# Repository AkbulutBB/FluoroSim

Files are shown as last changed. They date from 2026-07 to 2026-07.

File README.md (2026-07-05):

# FluoroSim 2.0 — gVXR Synthetic Fluoroscopy Navigation

Radiation-free pedicle screw placement training. Synthetic AP + lateral X-ray
images are generated directly from CAD/STL using **gVXR**, with a two-cube
ArUco probe tracked by two webcams and overlaid in real time.

No real fluoroscopy. No DLT calibration. No image-intensifier distortion. The
entire coordinate chain is defined in CAD, so every projection is exact.

---

## Why this architecture

The previous DLT-from-real-fluoroscopy approach was floored at 11–15 px
reprojection error by image-intensifier distortion (pincushion + S-distortion)
that cannot be estimated from 8 sparse fiducials. gVXR sidesteps this entirely:
the X-ray is **generated** from the STL with exact pinhole geometry, so the
3D→2D projection is analytically known and invertible. The steel bearings now
appear in the synthetic image at their exact CAD positions as a built-in
visual sanity check.

---

## Coordinate chain (zero physical calibration)

```
Camera  ──[ChArUco detect]──►  Board frame
Board   ──[BOARD_TO_WORLD]──►  gVXR world = CAD platform origin
World   ──[hard-stop slide]──► Spine STL origin
```

Every transform is exact by design. The only value you measure is
`BOARD_TO_WORLD` — and that comes from Fusion, not from a calibration session.

---

## Install

```bash
pip install opencv-contrib-python==4.9.0.80 numpy Pillow gvxr
```

`opencv-contrib-python` is pinned to 4.9.0.80 for numpy<2 compatibility in
the Anaconda base environment. gVXR provides `gvxrPython3`.

---

## First-run setup

### 1. Export STLs from Fusion 360
File → 3D Print → STL, units = **millimetres**:
- `models/spine.stl`
- `models/platform.stl` (optional)

### 2. Fill in CAD values in `config.py`
Four things, all read from your Fusion assembly:

| Value | What it is |
|---|---|
| `BEARING_POSITIONS` | (X,Y,Z) of each steel bearing centre in platform space |
| `SPINE_ORIGIN_IN_WORLD` | spine origin at its seated hard-stop position |
| `BOARD_TO_WORLD` | 4×4 rigid transform: ChArUco board origin → platform space |
| `SPINE_STL_PATH` / `PLATFORM_STL_PATH` | STL file locations |

### 3. Verify gVXR
```bash
python tools/test_gvxr.py
```
Should print `ALL TESTS PASSED` and produce `test_ap.png`, `test_lat.png`.

### 4. Calibrate both cameras (checkerboard intrinsics)
```bash
python tools/calibrate_intrinsics.py --device 0 --out data/intrinsics/cam0.npz
python tools/calibrate_intrinsics.py --device 1 --out data/intrinsics/cam1.npz
```

### 5. Print the probe markers
```bash
python tools/make_probe_sheet.py --out probe_sheet.pdf --dpi 300
```
Print at **100% scale** (no fit-to-page). Verify with the 50 mm scale bar.

---

## Run

```bash
python main.py
```

1. **Render X-ray Background** — generates AP + LAT from the STL (once, ~1–3 s)
2. **Start** — begins dual-camera tracking
3. Move the probe; its trajectory overlays live on both views (~5 Hz, 3 ms overlay)
4. **Photorealistic Snapshot** — re-renders with the K-wire as an actual
   tungsten/steel cylinder casting a true X-ray shadow (~2–10 s)

---

## Probe design (two stacked cubes)

- Two **40 mm cubes**, 5 mm spacer, 45 mm centre-to-centre pitch
- **32 mm** ArUco markers (DICT_4X4_50), one per side face, 4 faces per cube
- Bottom cube: IDs 0–3. Top cube: IDs 4–7.
- **100 mm K-wire** collinear with the probe axis, exiting the bottom cube's
  −Z face, tip 120 mm below the bottom-cube centre.

**Gluing rule:** Hold the probe handle-up / tip-down. The bottom edge of every
marker faces the K-wire tip. Both cubes oriented identically. Print cubes in
white PETG so the cube face itself serves as the ArUco quiet zone.

Fusing all visible faces from both cubes in a single solvePnP (plus VVS
refinement) gives far stronger angular constraints than any single face. Two
cameras at ~45° oblique (corner-on, each seeing two adjacent faces per cube)
constrain the pose best.

---

## Module map

```
config.py                 All geometry, camera, gVXR, and CAD parameters
main.py                   Entry point

core/
  camera.py               Threaded webcam capture + intrinsic I/O
  markers.py              BoardTracker + ProbeTracker (ChArUco + two-cube)
  navigation.py           Dual-camera pose fusion → world-space tip/base
  xray_sim.py             gVXR wrapper: render + analytic overlay + snapshot

ui/
  app.py                  Tkinter app: previews + AP/LAT panels + live overlay

tools/
  test_gvxr.py            gVXR install + render verification
  calibrate_intrinsics.py Checkerboard intrinsic calibration
  make_probe_sheet.py     A4 marker sheet with round-trip self-check

models/                   spine.stl, platform.stl  (your CAD exports)
data/
  intrinsics/             cam0.npz, cam1.npz  (saved calibration)
```

---

## gVXR 2.1 initialisation order (important)

gVXR is strict about call order — deviating produces silently all-zero images
with no error. The required sequence (handled inside `xray_sim.py`):

1. `createNewContext`
2. Create meshes / assign materials / position them
3. `setSourcePosition` → `usePointSource`
4. `resetBeamSpectrum` → `addEnergyBinToSpectrumPerPixelAtSDD`
   (`setMonoChromatic` and `addEnergyBinToSpectrum` are deprecated)
5. `setDetectorPosition` → `setDetectorUpVector`
6. `setDetectorNumberOfPixels` → `setDetectorPixelSize`
7. `addPolygonMeshAsOuterSurface` (register meshes — **after** steps 3–6)
8. `computeXRayImage`

To switch views, redo 3–6 and recompute; registered meshes persist.

On Windows/Anaconda set `GVXR_CONTEXT = "OPENGL"`; on a headless Linux box use
`"EGL"`.

---

## Error budget

| Source | Contribution |
|---|---|
| Spine hard-stop play | ≤ 1 mm (consistent, could be zeroed in CAD) |
| Probe reprojection (two-cube, dual-cam) | target < 15 px → ~ sub-mm tip |
| CAD-defined transforms | exact |
| **Total target** | **< 5 mm, < 5°** |

---

*Reference for marker-based AR neuronavigation methods: Yavas et al.,
Neurosurg Focus 2021.*

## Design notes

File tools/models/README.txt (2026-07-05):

Place your CAD exports here:
  spine.stl      (required — export from Fusion 360 in mm)
  platform.stl   (optional)

If spine.stl is missing, the simulator falls back to a cuboid placeholder
so you can test the pipeline before exporting.

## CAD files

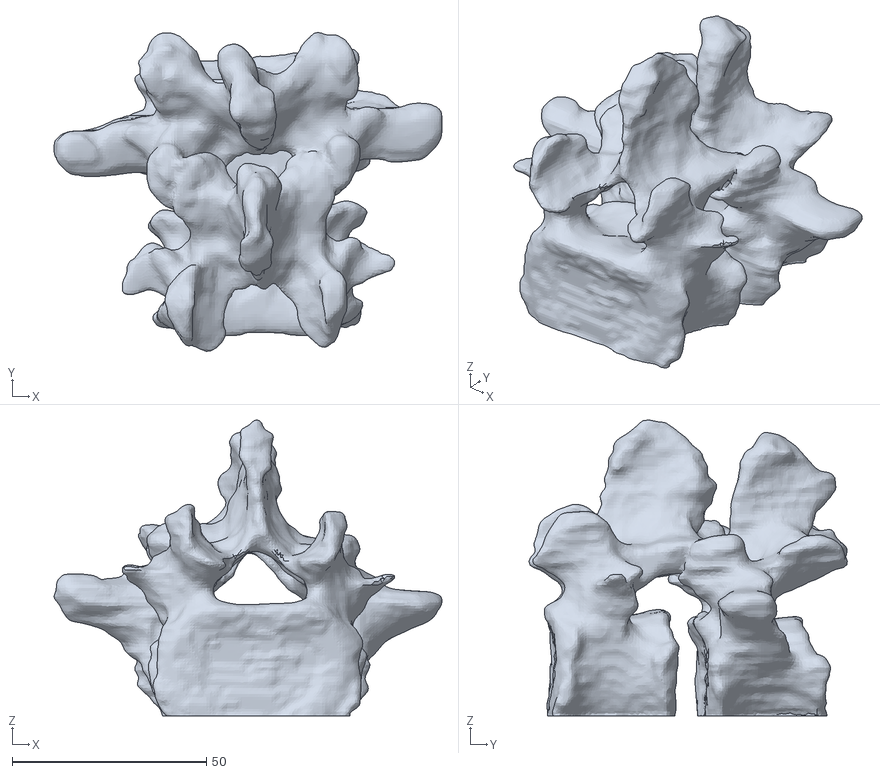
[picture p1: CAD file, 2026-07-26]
outputs/render_cache/spine_clipped.stl
99.8 x 82.0 x 76.1

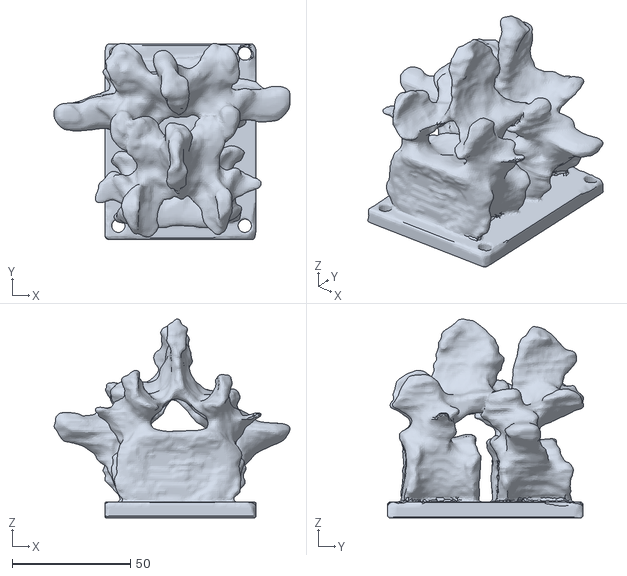
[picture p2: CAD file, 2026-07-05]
tools/models/spine.stl
99.8 x 83.0 x 84.1

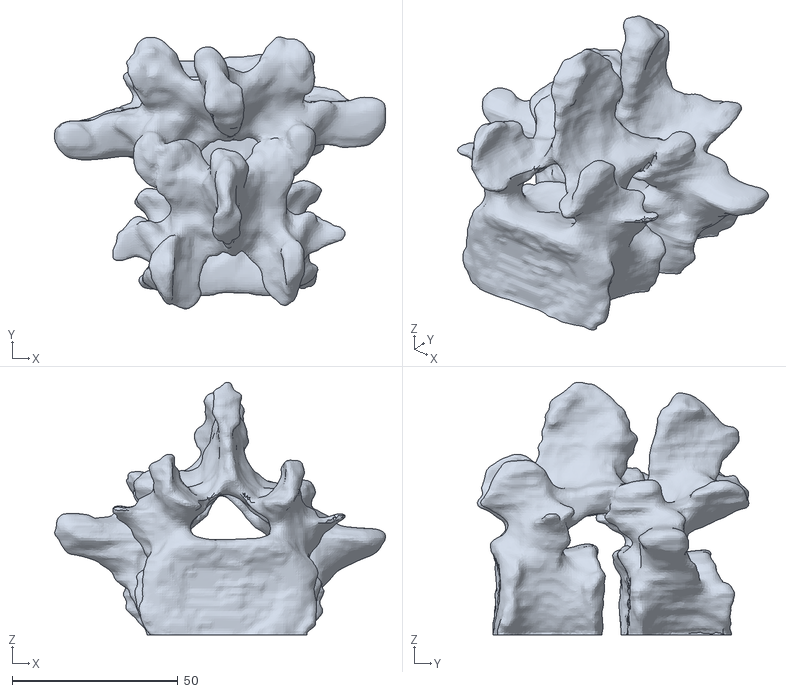
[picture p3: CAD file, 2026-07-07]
tools/outputs/stl_preview/spine_shell.stl
99.8 x 82.0 x 76.1

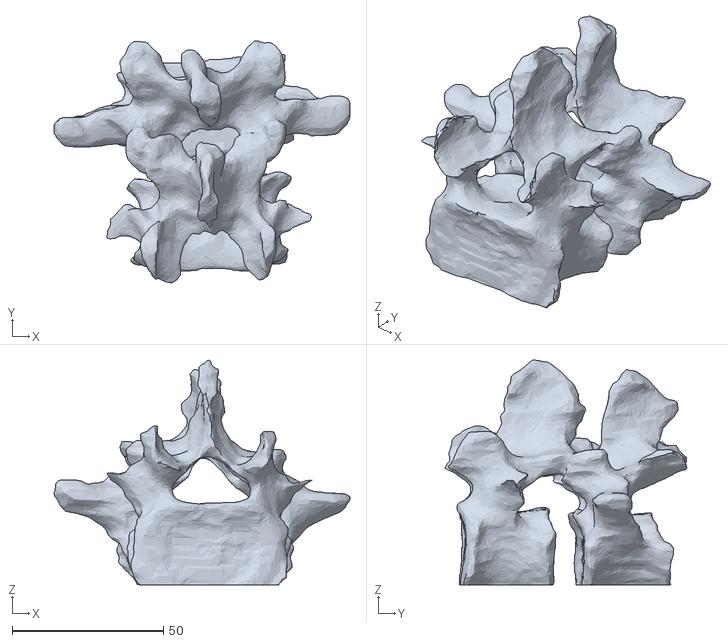
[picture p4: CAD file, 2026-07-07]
tools/outputs/stl_preview/spine_core.stl
97.9 x 80.1 x 74.3

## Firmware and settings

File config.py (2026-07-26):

"""
config.py — FluoroSim complete configuration.

All physical measurements in millimetres.

SETUP CHECKLIST
===============
Before first run, fill in the sections marked  ← FROM CAD  by reading the
values from your Fusion 360 assembly.  Everything else works as-is.

1. Export STLs from Fusion (File → 3D Print → STL, units = mm):
       models/spine.stl
       models/platform.stl   (optional)

2. Fill in BEARING_POSITIONS from Fusion assembly coordinates.
3. Fill in SPINE_TO_WORLD (spine local->platform rigid transform, rotation
   included -- do NOT assume translation-only; see derivation notes below).
4. Fill in BOARD_TO_WORLD (ChArUco board origin + orientation in platform frame).
5. Run tools/test_gvxr.py — confirm "ALL TESTS PASSED".
6. Run main.py.
"""

import cv2
import numpy as np

# ─────────────────────────────────────────────────────────────────────────────
# ArUco / ChArUco dictionaries
# ─────────────────────────────────────────────────────────────────────────────

ARUCO_PROBE_DICT_ID   = cv2.aruco.DICT_4X4_50
ARUCO_PROBE_DICT      = cv2.aruco.getPredefinedDictionary(ARUCO_PROBE_DICT_ID)

CHARUCO_BOARD_DICT_ID = cv2.aruco.DICT_5X5_50
CHARUCO_BOARD_DICT    = cv2.aruco.getPredefinedDictionary(CHARUCO_BOARD_DICT_ID)

# ─────────────────────────────────────────────────────────────────────────────
# ChArUco platform board
# ─────────────────────────────────────────────────────────────────────────────

CHARUCO_COLS        = 7      # number of squares horizontally
CHARUCO_ROWS        = 4      # number of squares vertically
CHARUCO_SQUARE_MM   = 18.0   # physical square side length (mm)
CHARUCO_MARKER_MM   = 13.5   # printed ArUco marker size inside each square
                              # (= 0.75 × square; adjust to match your print)

# ─────────────────────────────────────────────────────────────────────────────
# Two-cube probe geometry
# ─────────────────────────────────────────────────────────────────────────────
#
# Probe body frame:
#   Origin = bottom cube centre (the cube adjacent to the K-wire)
#   +Z axis = pointing toward the top/handle cube
#   K-wire exits from the −Z face of the bottom cube, 100 mm long
#   Top cube centre is at +45 mm along Z (40 mm cubes, 5 mm spacer)
#
#   Marker IDs:
#     Bottom cube: four side faces, IDs 0–3  (+X, −X, +Y, −Y)
#     Top    cube: four side faces, IDs 4–7  (+X, −X, +Y, −Y)
#

CUBE_SIDE_MM   = 40.0    # cube side length (mm)
MARKER_SIZE_MM = 32.0    # marker printed size per face (mm)
CUBE_GAP_MM    = 45.0    # bottom→top cube centre distance (40 mm + 5 mm spacer)
ROD_LENGTH_MM  = 100.0   # K-wire length from bottom cube face to tip

_h = MARKER_SIZE_MM / 2.0   # half marker side = 16 mm
_s = CUBE_SIDE_MM   / 2.0   # half cube side   = 20 mm
_g = CUBE_GAP_MM             # 45 mm

# ── Per-cube yaw about the probe long axis (+Z) ──────────────────────────────
# One cube is physically mounted rotated 45 deg relative to the other, so that
# any camera sees TWO faces per cube (corner-on) instead of one face-on. This
# gives more independent angular constraints in the joint PnP solve.
#
# Only the RELATIVE yaw between the two cubes affects accuracy. A global yaw of
# the whole probe is harmless here because the K-wire is coaxial with +Z
# (ROD_TIP_IN_PROBE lies on the Z axis), so rotating the entire probe about Z
# changes neither the tip position nor the trajectory direction.
#
# SIGN IS NOT YET FIELD-VERIFIED. +45 and -45 differ by 90 deg, which is a
# relabeling of which marker ID sits on which face — so a wrong sign is a real
# error in the model of the cubes' RELATIVE orientation, and it will corrupt any
# solve that uses markers from both cubes at once. It is easy to detect and fix:
# see "Verifying the yaw sign" below.
PROBE_CUBE_BOTTOM_YAW_DEG = 45.0   # cube with the K-wire — mounted corner-on
PROBE_CUBE_TOP_YAW_DEG    = 0.0    # handle-side cube — faces axis-aligned

# Verifying the yaw sign
# ----------------------
# Watch the probe reprojection RMS reported by the tracker while holding the
# probe so BOTH cubes are visible to one camera:
#   * low, stable RMS (a few px)      -> relative yaw is modeled correctly
#   * large RMS, or RMS that is fine  -> relative yaw is off by 90 deg;
#     on single-cube views but jumps     flip the sign below to -45.0
#     when the second cube appears
# Single-cube RMS looks fine under either sign, so judge it only on frames
# where both cubes are detected.
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

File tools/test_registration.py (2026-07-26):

"""
tools/test_registration.py — Registration sanity check, no hardware required.

Unlike stl_xray_preview.py (which deliberately ignores BOARD_TO_WORLD and
SPINE_TO_WORLD to test the spine STL/material in isolation), this script
renders the REAL config.py exactly as main.py's live app would — spine
mesh placed via SPINE_TO_WORLD, bearings placed via BEARING_POSITIONS, both
in the same gVXR world frame — but with zero camera, board, or probe
involved. It answers one question: "given today's config.py values, does
the spine + bearing geometry actually look/measure like a coherent scene?"

Run this AFTER tools/test_gvxr.py (confirms gVXR itself works) and BEFORE
main.py (which additionally needs cameras, an intrinsic calibration, and
the physical rig).

Checks performed
-----------------
1. Renders AP + lateral backgrounds (spine + 8 bearings) via the real
   XRaySimulator(config) — the exact same call ui/app.py makes.
2. Numerically projects every BEARING_POSITIONS entry through both views'
   pinhole geometry and reports whether each lands inside the detector
   frame. A bearing projecting off-frame usually means GVXR_ISOCENTER is
   far from where the bearings/spine actually are, not a rendering bug.
3. Reports the spine mesh's world-space bounding box (via trimesh, if
   installed) so you can eyeball whether it's anywhere near the bearings
   and isocentre, before even opening the PNGs.

Usage
-----
    python tools/test_registration.py

Output
------
    outputs/registration_test/ap_background.png
    outputs/registration_test/lat_background.png

What to look for in the PNGs
-----------------------------
- Bearings should appear as small bright dots roughly along the spine's
  periphery (not floating in empty background space, not buried deep
  inside/outside the visible anatomy).
- AP and LAT should look like two different projections of the SAME
  object, not two unrelated renders.
- If the spine is offset far to one side or mostly/entirely off-frame,
  SPINE_TO_WORLD is very likely still wrong (check rotation sign/axis
  first — that's the part solved from the fewest points).
"""

from __future__ import annotations

import sys
from pathlib import Path

import cv2
import numpy as np

sys.path.insert(0, str(Path(__file__).resolve().parents[1]))

import config as cfg  # noqa: E402
from core.xray_sim import XRaySimulator, GVXR_AVAILABLE  # noqa: E402

# Bearings live on the platform, not the spine, and are off by default for
# trainee-facing renders -- but they are the whole point of this test, so
# force them on for this run only.
cfg.RENDER_BEARINGS = True

try:
    import trimesh
    TRIMESH_AVAILABLE = True
except ImportError:
    trimesh = None  # type: ignore
    TRIMESH_AVAILABLE = False

OUTDIR = Path("outputs/registration_test")

# BGR (OpenCV order)
GREEN = (0, 255, 0)


def annotate_bearings(gray: np.ndarray, carm, bearings, world_to_spine) -> np.ndarray:
    """
    Draw a labelled green ring at each bearing's ANALYTICALLY projected pixel
    position on a colour copy of the grayscale render.

    gVXR output is an X-ray attenuation map — single-channel by physics — so a
    bearing cannot be "coloured" inside the render itself. Instead we project
    each bearing's known CAD position through the same pinhole geometry the
    renderer used (VirtualCArm.project_point) and mark it.

    This doubles as an independent cross-check: the ring is computed from the
    transform chain + projection maths, while the white dot underneath it comes
    from gVXR's ray-casting through the actual sphere mesh. If ring and dot
    coincide, both paths agree. If they are offset, one of them is wrong — and
    the pixel gap is a direct readout of the registration error.
    """
    rgb = cv2.cvtColor(gray, cv2.COLOR_GRAY2BGR)
    n_drawn = 0
    for b in bearings:
        pos_world = np.append(np.asarray(b["position_mm"], dtype=np.float64), 1.0)
        pos_render = (np.asarray(world_to_spine, dtype=np.float64) @ pos_world)[:3]
        px = carm.project_point(pos_render)
        if px is None:
            continue
        col, row = px
        # Ring, not filled disc — so the rendered bearing stays visible inside.
        cv2.circle(rgb, (col, row), 10, GREEN, 1, cv2.LINE_AA)
        cv2.putText(rgb, str(b["label"]), (col + 14, row + 4),
                    cv2.FONT_HERSHEY_SIMPLEX, 0.4, GREEN, 1, cv2.LINE_AA)
        n_drawn += 1
    cv2.putText(rgb, f"{n_drawn} bearing(s) in frame", (8, 20),
                cv2.FONT_HERSHEY_SIMPLEX, 0.45, GREEN, 1, cv2.LINE_AA)
    return rgb


def main() -> int:
    if not GVXR_AVAILABLE:
        print("gvxrPython3 is not importable in this environment. "
              "Run tools/test_gvxr.py first.", file=sys.stderr)
        return 1

    print("=" * 60)
    print("FluoroSim — Registration Sanity Check (no hardware)")
    print("=" * 60)

    spine_path = Path(cfg.SPINE_STL_PATH)
    print(f"Spine STL     : {spine_path}  "
          f"({'found' if spine_path.exists() else 'MISSING -> cuboid placeholder will be used'})")
    print(f"BOARD_TO_WORLD:\n{np.round(np.asarray(cfg.BOARD_TO_WORLD), 3)}")
    print(f"SPINE_TO_WORLD:\n{np.round(np.asarray(cfg.SPINE_TO_WORLD), 3)}")
    print(f"BOARD_TO_SPINE (derived, render frame):\n"
          f"{np.round(np.asarray(cfg.BOARD_TO_SPINE), 3)}")
    print(f"Isocentre     : {cfg.GVXR_ISOCENTER if cfg.GVXR_ISOCENTER is not None else 'AUTO (clipped spine bbox centre)'}")
    print(f"Baseplate clip: {cfg.SPINE_CLIP_MM} mm along local {cfg.SPINE_CLIP_AXIS}")
    print(f"Bearings      : {len(cfg.BEARING_POSITIONS)} configured")

    if TRIMESH_AVAILABLE and spine_path.exists():
        try:
            m = trimesh.load_mesh(str(spine_path), force="mesh")
            print(f"Spine bbox (spine-local = RENDER frame, unclipped): "
                  f"min={m.bounds[0].round(1)}  max={m.bounds[1].round(1)}")
        except Exception as exc:
            print(f"  (bbox check skipped: {exc})")

    # Where does the ChArUco board origin land in the render frame? This is the
    # single number that ties the tracker to the anatomy -- if it is nowhere
    # near the spine bbox above, the probe will render in the wrong place.
    board_origin_render = (np.asarray(cfg.BOARD_TO_SPINE)
                           @ np.array([0.0, 0.0, 0.0, 1.0]))[:3]
    print(f"ChArUco origin in render frame: {board_origin_render.round(2)}")

    OUTDIR.mkdir(parents=True, exist_ok=True)

    sim = XRaySimulator(cfg)
    print("\nInitialising gVXR context + scene ... ", end="", flush=True)
    if not sim.initialise():
        print("FAILED — see log above.", file=sys.stderr)
        return 1
    print("OK")

    print("Rendering AP + lateral (spine + bearings) ... ", end="", flush=True)
    ap_img, lat_img = sim.render_background()
    if ap_img is None or lat_img is None:
        print("FAILED — render_background() returned None.", file=sys.stderr)
        sim.shutdown()
        return 1
    print("OK")

    ap_path = OUTDIR / "ap_background.png"
    lat_path = OUTDIR / "lat_background.png"
    cv2.imwrite(str(ap_path), ap_img)
    cv2.imwrite(str(lat_path), lat_img)

    # Annotated copies: green labelled rings at the analytically projected
    # bearing positions. Compare ring vs rendered white dot -- see docstring.
    w2s = np.asarray(cfg.WORLD_TO_SPINE, dtype=np.float64)
    ap_annot_path = OUTDIR / "ap_background_bearings.png"
    lat_annot_path = OUTDIR / "lat_background_bearings.png"
    cv2.imwrite(str(ap_annot_path),
                annotate_bearings(ap_img, sim._ap, cfg.BEARING_POSITIONS, w2s))
    cv2.imwrite(str(lat_annot_path),
                annotate_bearings(lat_img, sim._lat, cfg.BEARING_POSITIONS, w2s))

    # ── Numeric bearing-projection check ────────────────────────────────
    print("\nBearing projection check:")
    npix = cfg.GVXR_DETECTOR_PIXELS
    n_in_ap = n_in_lat = 0
    w2s = np.asarray(cfg.WORLD_TO_SPINE, dtype=np.float64)
    for b in cfg.BEARING_POSITIONS:
        pos_world = np.append(np.array(b["position_mm"], dtype=np.float64), 1.0)
        pos = (w2s @ pos_world)[:3]   # into the spine-local render frame
        px_ap = sim._ap.project_point(pos)
        px_lat = sim._lat.project_point(pos)
        in_ap = px_ap is not None
        in_lat = px_lat is not None
        n_in_ap += in_ap
        n_in_lat += in_lat
        print(f"  {b['label']:<14} render={tuple(pos.round(1))}  "
              f"AP={'in-frame ' + str(px_ap) if in_ap else 'OFF-FRAME'}  "
              f"LAT={'in-frame ' + str(px_lat) if in_lat else 'OFF-FRAME'}")

    sim.shutdown()

    print(f"\n{n_in_ap}/{len(cfg.BEARING_POSITIONS)} bearings in-frame on AP, "
          f"{n_in_lat}/{len(cfg.BEARING_POSITIONS)} on LAT "
          f"(detector {npix[0]}x{npix[1]} px)")
    fov_mm = npix[0] * cfg.GVXR_PIXEL_SIZE_MM
    print(f"\nSaved: {ap_path}")
    print(f"Saved: {lat_path}")
    print(f"Saved: {ap_annot_path}   <- green labelled bearing rings")
    print(f"Saved: {lat_annot_path}  <- green labelled bearing rings")

    print(f"\nNote: the detector covers only ~{fov_mm:.0f} x {fov_mm:.0f} mm "
          f"({npix[0]}px x {cfg.GVXR_PIXEL_SIZE_MM} mm/px), centred on the "
          f"spine. The bearings are pressed into the PLATFORM walls, which span "
          f"a much wider footprint than that -- so most of them physically "
          f"cannot appear in frame. Few/no bearings visible is EXPECTED here and "
          f"is not evidence of a registration error.")

    if n_in_ap < len(cfg.BEARING_POSITIONS) or n_in_lat < len(cfg.BEARING_POSITIONS):
        print("\n[INFO] Not all bearings are in-frame on both views (see note above).")

    print("\nWhat to check in the *_bearings.png images:")
    print("  For any bearing that IS in frame, the green ring (analytic")
    print("  projection of its CAD position) should sit directly on top of the")
    print("  small bright dot (gVXR's ray-cast through the actual sphere mesh).")
    print("  Coincident  -> transform chain and projection maths agree.")
    print("  Offset      -> the pixel gap is your registration error readout.")
    print("\nThe decisive end-to-end test is still the probe: put it in the")
    print("platform hole and use the Snapshot button in main.py.")
    return 0


if __name__ == "__main__":
    sys.exit(main())

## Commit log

2026-07-05 gvxr trials
    [spine.stl]
2026-07-05 fixyfix- it is fixed.
    [clipped_preview.stl, repaired_source.stl]
2026-07-07 fixed core-shell thing
    [clipped_preview.stl, repaired_source.stl, spine_core.stl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]
